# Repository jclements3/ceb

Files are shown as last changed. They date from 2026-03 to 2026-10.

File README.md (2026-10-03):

# CINVA-Ram Block Press

OpenSCAD model of a CINVA-Ram compressed earth block press.
All dimensions in inches. Material: 1/4" (0.250") steel plate unless noted.

Primary file: `cinva_ram.scad`

**14 x 7 x 4 shop drawings (recommended: the simple press).** `cinva_simple.py` is a faithful scale-up of the permies.com replica (thread 33406). His part drawings are `cinva1-7.jpg`; his SketchUp model and video show the assembly. Every part is scaled from his 11.5 x 6 x 3-5/8 brick (lengths x 1.217, widths x 1.167, heights x 1.102).

How it works:
- **Pressing:** the cam pin on his L-shaped head drops into the scoops at the peak of his V ramps. Pulling the handle over swings pin Q up over the cam pin like a knee, lifting the piston through the yoke. It locks 3 degrees past straight.
- **Latch:** his hook plates latch the head to the yoke for tilting.
- **Eject:** the yoke leans on his fixed pins, and pushing the handle down lifts the brick out.

Fixes to his drawings:
- the 2" side slot (his error; the supplier changed it to 1"), cut to pin + 1/16;
- the slot top kept below the loose soil;
- the fixed-pin height set for the eject stroke.

Heavier stock (listed with reasons in `ASSEMBLY.md`):
- 5/8 side plates;
- 3/4 AR400 ramps;
- 4140 pins (P 1-3/4", Q 1-1/4", cam 1-3/8");
- 3 x 1/2 yoke arms;
- the lid narrowed so the head clears it.

Checked at 150 psi working, 306 psi design (rev D: was 200 psi working):
- peak pull 98 lbf on the 90 in, 2 in sch 160 handle (rev G), under the 120 lbf CCOHS limit for pulling
  down above head height; 190 lbf if the soil needs 290 psi;
- about 92 lbf to eject (rev E: was 112);
- 23 part types, about 248 lb of steel;
- the press bolts to a 12 in welded steel stand (rev F, items 39-42, about 56 lb; Step 10 of `ASSEMBLY.md`);
- a feeder (rev C, items 24-38, about 53 lb): a funnel on a sliding feed box with a knife-gate floor,
  parked beside the press and slid over the mold to fill; see Step 9 of `ASSEMBLY.md`.

`cinva_ram_b123d.py` is the earlier heavy-duty version, kept for reference. It has a concave roller track, a central claw latch, and an eject roller on posts; its guide is `ASSEMBLY_full.md` and its drawings are in `drawings/14x7x4/`. Both models:
- solve the linkage for the fill, compress and eject positions;
- check every position and motion for collisions;
- run first-order strength checks.

`cinva_drawings.py` produces the ISO 128 set: general assembly with parts list, assembly views, operating positions, operation and design data, one detail sheet per part, DXF cut files, a PDF and a STEP assembly.

```
LD_LIBRARY_PATH=$HOME/miniconda3/lib python3 cinva_simple.py --check            # summary, strength and clearance checks
LD_LIBRARY_PATH=$HOME/miniconda3/lib python3 cinva_drawings.py --model simple   # -> drawings/simple-14x7x4/
LD_LIBRARY_PATH=$HOME/miniconda3/lib python3 cinva_animation.py                 # -> animation/press.json (simple press)
cd animation && python3 -m http.server   # then open http://localhost:8000 (#p5 jumps to phase 5, ?full shows the heavy press)

LD_LIBRARY_PATH=$HOME/miniconda3/lib python3 cinva_ram_b123d.py --check         # heavy-duty version
LD_LIBRARY_PATH=$HOME/miniconda3/lib python3 cinva_drawings.py --model full     # -> drawings/14x7x4/
LD_LIBRARY_PATH=$HOME/miniconda3/lib python3 cinva_animation.py --model full    # -> animation/press-full.json
```

The OpenSCAD model below (`cinva_ram.scad`) is the older interpretation of the scanned drawings; its lever geometry does not actually move the piston through a compression stroke.

## Parts by Assembly

### Brown — Pivot assembly (moves along ramp)
| Part | Description |
|---|---|
| **Pivot**  | Solid 2x2x6 block — holds handle, wings/tails pivot around it |
| **Wing** | Long toggle link (2 holes) — connects spacer pin to roller pin  |
| **Tail** | Short toggle link (1 hole) — connects spacer pin to pivot block |
| **Handle** | 6' round bar in pivot sunk hole (cylinder, no module) |

### Orange — Lever assembly (pivots around load pin)
| Part | Description |
|---|---|
| **Lever bar** | Long arm the operator pulls to press the brick (inline, `lever_bar_profile()`) |
| **Cross** | Cross bars welded between lever bars at grip end (inline cubes) |
| **Lever spacer block** | Block between crosses with roller hole (inline cube) |

### Pink — Clamp (rotates on axle)
| Part | Description |
|---|---|
| **Clamp**  | Hook-shaped bracket on axle that grabs the cross to lock the lever |
| **Grabber** | Plate between left and right clamp brackets |

### Purple — Pins and bars (round stock)
| Part | Description |
|---|---|
| **Fulcrum Pin** | Fixed pin through side plate holes |
| **Load Pin** | Pin in side slots, rises with lever mechanism |
| **Roller** | Rolls along ramp surface, drives the lever |
| **Spacer Pin**  | Through pivot/wing upper holes, moves with assembly  |
| **Axle** | 7/16" pin through front block, clamp rotates on this |

### Teal — Shelf assembly (rises to press brick)
| Part | Description |
|---|---|
| **Shelf** | Flat plate the brick sits on, rises in the side slots |
| **Bracket** | Vertical brace under shelf, connects shelf to piston plates |
| **Piston**  | Vertical plate pair connecting shelf to load pin |

### Red — Ramps and Top
| Part | Description |
|---|---|
| **Top**  | Flat plate on top of side plates — ramps sit on this |
| **Ramp** | V-shaped profile the roller rolls along to convert pull into downward press |

### Gray (ghost) — Structure
| Part | Description |
|---|---|
| **Side** | Tall vertical plate with piston slot, bolted to feet |
| **EndPlate** | Plate welded to shelf front/back edges, forms the brick chamber |

### White — Hinge (Top+Ramps swing open to eject brick)
| Part | Description |
|---|---|
| **Receiver** | Cylinder with 0.5" hole welded to Side plate — receives the pin |
| **Tab** | Tapered bracket welded to Top plate — butts against Ramp, conforms to Receiver |
| **Pin** | 0.5" dia cylinder welded to Tab, drops into Receiver |

### Green — Base
| Part | Description |
|---|---|
| **Base_Bracket** | L-shaped feet — bolts to ground, side plates mount to vertical leg |

## Animation

The model animates with OpenSCAD's `$t` variable (0 to 1):
- **t=0**: Roller at right side of ramp, lever tilted right
- **t=0.5**: Roller near peak, lever nearly vertical
- **t=1**: Roller past peak on left slope, lever tilted left

To render specific frames from the command line:
```
openscad -o frame.png -D '_t_override=0.5' cinva_ram.scad
```

## DXF Export

Run `export_dxf.sh` to export 2D projections of all parts as DXF files in `./dxf/`:
```
bash export_dxf.sh
```

## Reference Drawings

| Drawing | Description |
|---|---|
| cinva1.jpg | Sheet 1 — EndPlate (brick chamber walls) |
| cinva2.jpg | Sheet 2 — Wing and Tail (toggle links) |
| cinva3.jpg | Sheet 3 — Clamp bracket |
| cinva4.jpg | Sheet 4 — Lever bars and cross bars |
| cinva5.jpg | Sheet 5 — Ramp profile |
| cinva6.jpg | Sheet 6 — Side plate details |
| cinva7.jpg | Sheet 7 — Side plate and Piston |

## Reference Photos

| Photo | Description |
|---|---|
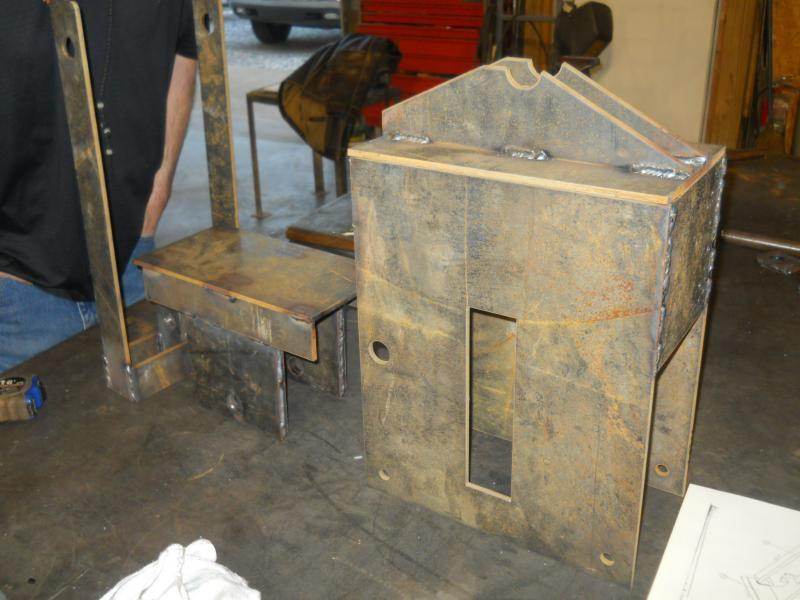
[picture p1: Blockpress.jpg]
|  | Baseboard frame and mold box sub-assemblies before final assembly |
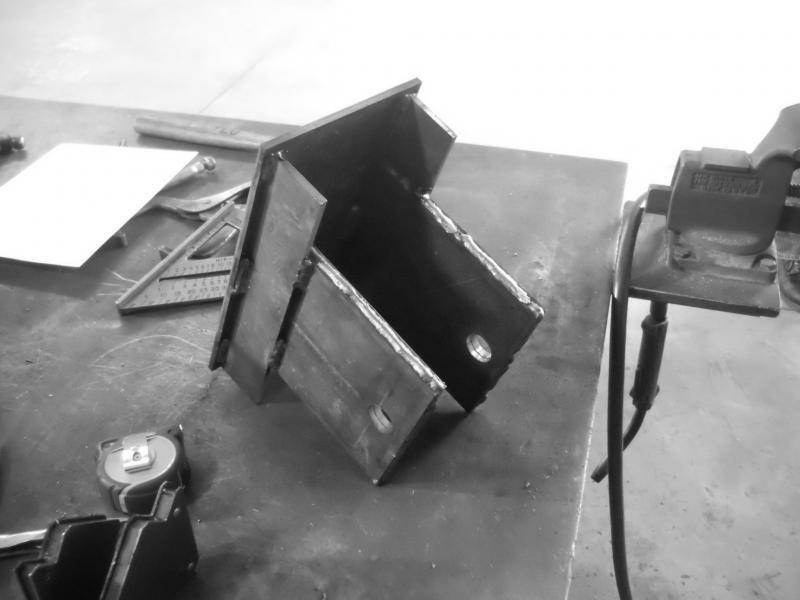
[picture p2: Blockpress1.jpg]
|  | Mold box welded, cover open showing hinge and interior |
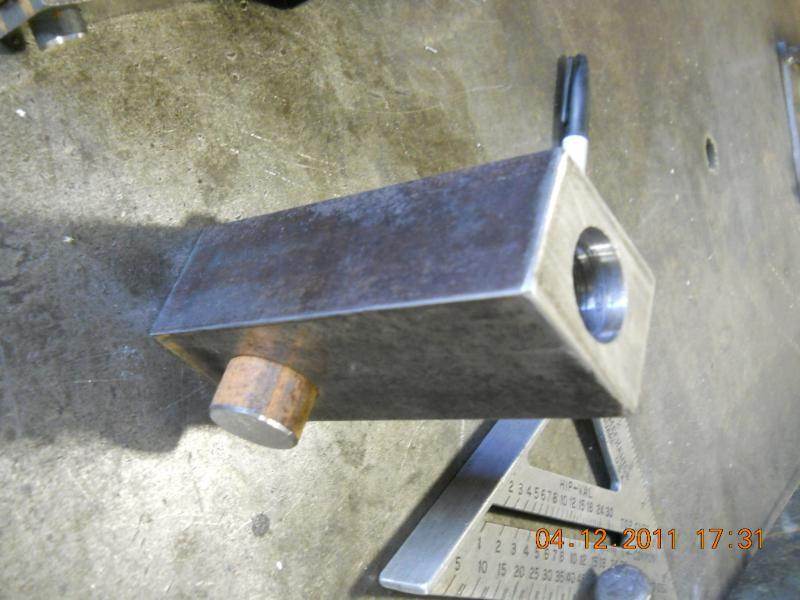
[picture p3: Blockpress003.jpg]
|  | Piston body close-up — rectangular with pivot hole and bronze bushing |
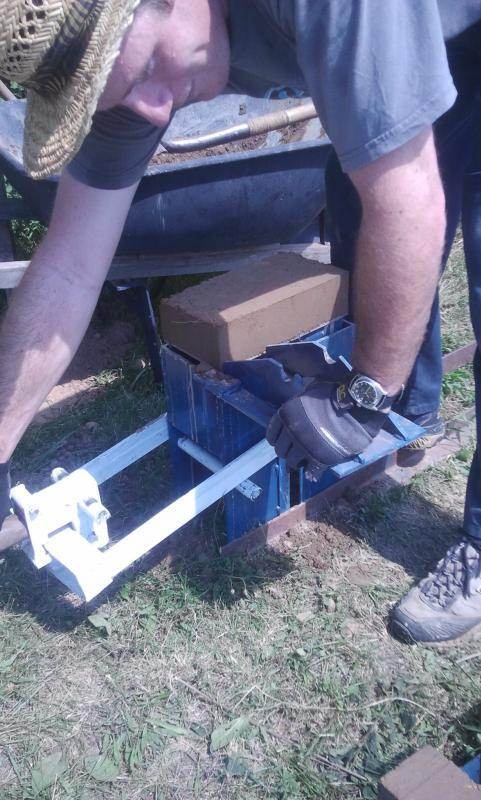
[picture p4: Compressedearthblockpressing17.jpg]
|  | Complete press in use, ejecting a compressed earth block |

---

# CETA-RAM Brick Making Machine

OpenSCAD and FreeCAD models of the CETA-RAM compressed earth block press,
based on the OHO e.V. engineering drawings (CC-BY-SA 4.0).

Brick size: **12" x 6" x ~4"** (compressed)

## Files

| File | Description |
|---|---|
| `ceta-ram/ceta_ram.scad` | OpenSCAD model — metric (mm), all 6 assemblies |
| `ceta-ram/ceta_ram_imperial.scad` | OpenSCAD model — imperial (inches), US steel sizes |
| `ceta-ram/ceta_ram_imperial.py` | FreeCAD Python macro — imperial, parametric |
| `ceta-ram/CETA_RAM_Imperial.FCStd` | Pre-built FreeCAD file (open directly) |
| `ceta-ram/CETA-RAM_Reference.md` | Complete BOM and dimensions from OHO drawings |

## Imperial Steel Sizes

| Metric | Imperial | Use |
|---|---|-----|
| 13mm plate | 1/2" | Sides, supports, brackets |
| 10mm plate | 3/8" | Base, top, piston plates |
| 6mm plate | 1/4" | Cap plate, side levers |
| 152x52x8 C-channel | C6x8.2 | Beams (2 pcs @ 18") |
| ∅60 rod | 2-3/8" | Main bars (2 pcs @ 18") |
| ∅44 rod | 1-3/4" | Handle (17-3/4") |
| ∅32 rod | 1-1/4" | Pins and rods |
| ∅20 rod | 3/4" | Support rod |
| ∅12 rod | 1/2" | Small pin |
| ∅70/60 tube | 2-3/4" OD / 2-3/8" ID | Piston rods |
| ∅44/32 tube | 1-3/4" OD / 1-1/4" ID | Piston rod 1, cap |
| ∅50/32 tube | 2" OD / 1-1/4" ID | Bushings |
| ∅40/20 tube | 1-1/2" OD / 3/4" ID | Support tubes |
| 2"x2"x1/4" angle | — | Cover levers (2 pcs @ 9-1/16") |
| M12/M14 bolts | 1/2"-13 | All fasteners |

## CINVA-Ram vs CETA-RAM Comparison

Both presses make a **12" x 6" x ~4"** brick, but the CETA-RAM produces
**cored bricks** (two 2-3/4" holes) while the CINVA-Ram makes **solid bricks**.

### Brick Weight Comparison

| Brick Type | Weight |
|---|---|
| CINVA-Ram (solid) | 20.0 lb |
| CETA-RAM (empty cores) | 16.7 lb |
| CETA-RAM + foam fill | ~16.8 lb |
| CETA-RAM + concrete fill | 20.8 lb |

### Wall Weight (8' wide x 6' tall = 144 bricks)

| Wall Type | Weight |
|---|---|
| Solid CINVA-Ram | 2,880 lb |
| CETA-RAM + foam + 1 bond beam | 2,468 lb |
| CETA-RAM all grouted | 2,995 lb |

### Recommended Cabin Wall Assembly (CETA-RAM)

- **Cores filled with closed-cell foam** — adds insulation (earth alone is ~R-0.2/inch)
- **Bond beams every 6'** — one course of grouted cores with horizontal rebar
- **Bond beam at top** — distributes roof load, ties walls together
- Result: thermal mass on both faces + insulation in middle + structural bond beams
- ~400 lb lighter per 8' wall section vs solid bricks
- 3 lb lighter per brick = less fatigue over thousands of bricks

## Reference Data

| Source | Location |
|---|---|
| Engineering drawings (53 pages) | `ceta-ram/pdf/` |
| STEP files (6 sub-assemblies) | `ceta-ram/cad/STP-files/Stp/` |
| Autodesk Inventor files | `ceta-ram/cad/CAD-files/Cad/` |
| AutoCAD 2D drawings | `ceta-ram/cad/DWG-files/` |
| Photos/renders | `ceta-ram/images/` |

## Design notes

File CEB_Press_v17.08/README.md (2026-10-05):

# OSE CEB Press v17.08

Open Source Ecology's **CEB Press v17.08**, Prototype 9 (2017). This is the latest working build in OSE's
CEB press genealogy: the hydraulic "Liberator" line, after v16.09. It simplified how the drawer bushings
are mounted.

Source: https://wiki.opensourceecology.org/wiki/CEB_Press_v17.08 (CC BY-SA).

## Contents

| Path | What it is |
|---|---|
| `source/CEB_17.08_CAD_Assembly.fcstd` | OSE's FreeCAD assembly (A2plus): eight sub-assemblies stored as BREP shells (unzipped in `source/fcstd/`) |
| `source/CEB_v1708_CAM.zip` | OSE master CAM nests: 1/8, 1/4 and 1/2 plate DXFs |
| `source/CEB_DXFs.zip` | OSE individual-part DXFs (partial; some fail to import) |
| `source/Seamanandschuske.zip` | OSE's 1/2 plate order, nested on 5 x 10 sheets |
| `source/subassemblies/` | OSE's per-sub-assembly FreeCAD files (with named parts), part folders, DXFs, pictures and the wiki page (from JC's download) |
| `source/*.html` | Owner's manual and genealogy wiki pages |
| `v1708_drawings.py` | Builds the ISO 128 set from the FreeCAD model (build123d + `../cinva_drawings.py`) |
| `drawings/` | `sheets/*.svg`, `dxf/` (flat parts), `CEB_Press_v17.08.pdf`, `CEB_Press_v17.08.step`, `manifest.json` |
| `shaker/` | Soil shaker (hopper vibrator) from OSE's *CEB a-z Build 1.0* manual: `shaker.py`, plus its own `drawings/` |

## Drawing set

* Sheet 1: general assembly, with a balloon for each of the eight sub-assemblies (S1-S8).
* Sheets 2-9: one per sub-assembly (Frame, Hopper Seat, Main Cylinder, Drawer, Arms, Hopper, Grate,
  Secondary Cylinder), with balloons and a parts list.
* Then one detail sheet for each distinct part: 76 parts, 246 pieces in total.
  * Mirror pairs and identical parts are drawn once, with their quantity.
  * Each part is laid flat on its largest face.
  * Flat plates also get a DXF.

The part names did not survive in OSE's file, so parts are named `<sub-assembly> NN` with stock and size.
Before cutting, check each part against OSE's CAM nests in `source/CEB_v1708_CAM.zip`.

```
export LD_LIBRARY_PATH=$HOME/miniconda3/lib
python3 CEB_Press_v17.08/v1708_drawings.py            # full set (~8 min)
python3 CEB_Press_v17.08/v1708_drawings.py --only 1,40 --no-pdf
python3 CEB_Press_v17.08/shaker/shaker.py             # shaker set
```

## Shaker

The shaker is modelled from two OSE sources:
* *CEB a-z Build 1.0*, steps 3-5 (pp. 15-20);
* OSE's weldment drawings 001-0042..0048 and 001-0077, in `OSE/ceb_press_cnc_package/reference/weldment_drawings`.

Where the two disagree, the weldment drawing is used. The guard outline comes from the manual. The
assembly sheet's arrangement is indicative: it follows the section on weldment 001-0048, sheet 2.

## Generated files

STEP exports (`*/drawings/*.step`) are gitignored: each drawing script writes its STEP when run. The PDFs, SVG
sheets and DXFs are kept in the repo for the web page and for shops without a build123d setup.

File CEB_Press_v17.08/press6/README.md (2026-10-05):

# OSE CEB Press 6 (a-z Build 1.0) — ISO 128 drawing set

Open Source Ecology's **CEB Press 6** ("The Liberator", Prototype 6, 2013, the Beddingfield edition): the
machine of the *CEB a-z Build 1.0* manual (`../CEB_a-z_Build_1.0.pdf`) and its cost / cut list
(`../CEB Press.ods`). Drawn with build123d and the repo's ISO 128 sheet code (`../../cinva_drawings.py`).

```
export LD_LIBRARY_PATH=$HOME/miniconda3/lib
python3 CEB_Press_v17.08/press6/press6_drawings.py -j 2          # full set
python3 CEB_Press_v17.08/press6/press6_drawings.py --only 1,35 --no-pdf
```

Output: `drawings/sheets/*.svg`, `drawings/dxf/*.dxf` (flat parts), `drawings/CEB_Press_6.pdf`,
`drawings/CEB_Press_6.step` (inches, coloured by module), `drawings/manifest.json` (same schema as
`../drawings/manifest.json`, plus `title`, `pdf`, `step`, `source`, `naming`, `purchased`, `dxf_checks`).

## Sources

| Source | Used for |
|---|---|
| `OSE/ceb_press_cnc_package/reference/full_assembly.stp` (OSE 01-001-00-6 main assembly) | All geometry. Read with OCP's XCAF reader so OSE's product names survive: every solid carries its OSE part number (`01-XXX-00-X`) and, for CNC plates, its library label (`L-XX`). |
| `../CEB Press.ods`, sheet *Final Cut List* | Manual part names. Its part numbers `100XXX` are OSE `01-XXX`; a cut-list name is used only when one of its lengths agrees with the model (±0.6 in). |
| *CEB a-z Build 1.0* (Simple Plates, Frame components, drawer, press feet pages) | A few more manual names (brick holder / dirt keeper plates, controller plate, feet, legs, press feet). |
| `OSE/.../reference/drawing_index.md` | 2011-12 BOM descriptions, 2015 weldment numbers / descriptions / stock. |
| `OSE/.../reference/2d_drawings/*.pdf` titles | Names of the assemblies; plates without a description are named after the assembly they are welded into (e.g. "Chamber Wall Plate L-F9"). |
| `OSE/.../dxf/*_steel_library.dxf` (original, not the 14x7 variant) | Cross-check of every `L-XX` plate: flat size and thickness against the model, noted on each sheet. Bent sheet parts get their flat blank from the DXF. |

## Organisation

Sheet 1 general assembly (modules ballooned S1-S9) · sheets 2-10 one per module of the manual
(Main Frame, Press Cylinder and Foot, Arms, Feet and Legs, Drawer, Hopper, Grate, Soil Shaker, Controls) ·
then one detail sheet per OSE part number (identical parts once, with the total quantity; the module is the one
that uses it most, the notes list every use). Purchased parts (cylinders, valves, hinges, bushings, printed
plastic, couplers, fittings) and fasteners are in the STEP and listed on the module sheets / in the manifest, not
detailed. Fasteners are left out of the assembly views.

## Naming and checks

See `naming` and `dxf_checks` in `drawings/manifest.json` and the summary at the end of `build.log`.
* 84 OSE part numbers detailed (238 fabricated pieces in 9 modules); 486 STEP solids in all, 141 of them
  fasteners and 107 other purchased / printed parts.
* Part identity: 84 / 84 (100 %) from the STEP's own OSE part numbers and L-labels.
* Descriptive names: 47 / 84 from the a-z cut list (length-checked), the manual or OSE's drawing index;
  35 more named after the OSE assembly they are welded into (2D drawing title, e.g. "Saddle Plate L-Q3");
  2 left as "Part 01-xxx" / "Plate L-H19" (parts of 01-236, which has no OSE drawing).
* DXF cross-check: 67 L-labelled plates; 57 match the original CNC outline (size and thickness within
  0.06 in); 4 are bent 1/8 sheet parts (L-H4, L-H5, L-H10, L-H12; blank size from the DXF);
  L-A6, L-Q12, L-G1, L-G2 differ from the library outline (noted "CHECK" on their sheets);
  L-Q2 and L-H19 have no outline in the original libraries.

## Known gaps and inconsistencies

* OSE's 2D set title blocks say **"CEB PRESS 5"** although the package is Press 6 (top-level 01-001-00-6).
* **The a-z Build 1.0 manual builds a later, structural-shape version** of parts of this machine; these are
  in the manual / cut list but not in the STEP (the STEP is the CNC-plate machine):
  - soil shaker from L4x4 angle (21 in and 8 in), 1 in rebar braces and a 2x2-angle-framed guard — drawn
    separately in `../shaker/` (the STEP's shaker is the plate version, L-O2..L-O5, drawn here);
  - roller guides (V-groove bearings on a 1/2 x 2 x 16 main plate) — the STEP uses 1 in guide rods in printed
    / nylon bushings (01-220, 01-236);
  - drawer outer / inner rails (3/16 x 2-1/2 and 1/2 x 2 x 36), back (L4x7 angle), spacer (6x6 tube);
  - main-frame small components: sensor holders, magnet holder, thin / wide cylinder supports, dirt blockers
    (2x2 angle), horizontal-member reinforcements;
  - hopper mounting plates and hinge plates; legs 2x2x1/4 x 48 (STEP legs 01-155 are 3/16 wall x 36);
  - the electronics (sensor unit, solenoid driver, controller box) and hydraulic hoses.
* Several OSE part numbers are reused between the 2011-12 set and the a-z cut list for different stock
  (e.g. the frame channels L-F1 / L-F2 are 1/2 plate in the STEP, C6x13 in the 2015 weldment redraw and the
  cut list); each sheet draws the STEP part and notes the alternative.
* The STEP has the same part number on mirror-image parts (left / right primary arms share 01-009, 01-010,
  01-272); they are drawn once, quantity 2.
* L-labels in the DXF libraries but not in the STEP: L-D9 is in the STEP as 01-028-00-2; L-H7 and L-Q10 are
  printed-plastic parts; L-H14, L-O10, L-Q16 have no STEP part. L-O9 is in the STEP as 01-143, typed "L-09".

## Rebuilding from a fresh clone

`press6_drawings.py` uses OSE's files from `OSE/ceb_press_cnc_package/` (from `OSE/get_ceb_plans.sh`) when that
folder exists. Otherwise it fetches OSE's main-assembly STEP (`01-001-00-6.stp`), the 2D drawing set
(`CEBVI_2D_DRAWING_PDF.zip`) and the three CNC DXF libraries from the OSE wiki into `source/ose/`, which is
gitignored. The drawing cross-reference index (`source/drawing_index.md`) and the DXF cluster extractor
(`extract_parts.py`, from `OSE/freecad/`) are kept here. The STEP export in `drawings/` is not tracked: run the
script to make it.

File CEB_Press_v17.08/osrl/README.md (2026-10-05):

# OSRL "Resilient Living" CEB press, rev 1.1: build123d clone

This is a clone of the **Open Source Resilient Living CEB press, rev 1.1**:
* *OSRL CEB Press Drawings 1-1*: 11 sheets, Dec 2011, design team Damien Gendron and Butte Metz.
* The OSRL *Manual CEB Press*.
* Licence: CC BY-SA 3.0, www.osrliving.org.
* Source PDFs: `../pdfcoffee.com_osrl-ceb-press-drawings-1-1-2-pdf-free.pdf` and `../pdfcoffee.com_manual-ceb-press-pdf-free.pdf`.

It is a manual CINVA-type press for a 12 x 6 x 4 block with two 2-3/8 cores.
* **Frame:** two C6x13 channels on a base plate, with 1/4 side plates. Two 2 in pipe guide rods form the cores.
* **Piston:** a lower insert on two pipe guides, carried on a 1 in pin by a two-arm yoke.
* **Toggle and latch:** the toggle has a square-tube body that takes a 48 in pipe lever, and two 2 in followers. A latch hooks the lever to the yoke.
* **Lid:** hinged and counterweighted. Its two rails climb to a 2 in scoop that seats the followers.
* **Ejection:** the yoke tilts onto two eject rollers on the front channel.

## Files

| Path | What it is |
|---|---|
| `osrl_press.py` | Parametric model: every part on their 11 sheets, kinematics, poses, strength checks, functional checks and collision sweeps (`--check`) |
| `build_drawings.py` | ISO 128 drawing set built with `../../cinva_drawings.py`, output to `drawings/` |
| `drawings/` | `sheets/*.svg` (4 assembly sheets + 42 part sheets), `dxf/`, `OSRL-CEB-Press_12x6x4.pdf`, `.step`, `manifest.json` |
| `build_animation.py` | Exports `animation/press.json` |
| `animation/index.html` | The repo's three.js viewer, extended for the toggle pivot sitting off the yoke axis |
| `check.log` | Last `--check` results |

```
export LD_LIBRARY_PATH=$HOME/miniconda3/lib
python3 CEB_Press_v17.08/osrl/osrl_press.py --check      # summary, strength, functional checks, collision sweeps
python3 CEB_Press_v17.08/osrl/build_drawings.py          # ISO 128 set
python3 CEB_Press_v17.08/osrl/build_animation.py         # animation/press.json
cd CEB_Press_v17.08 && python3 -m http.server             # then open /osrl/animation/
```

## How the press works (as reconstructed)

1. **Stand up.** With the lever latched along the yoke, standing the yoke up rolls the followers up the rail slopes. They drop into the scoops with the piston still on the bottom (0.04 in off). This is the manual's "letting the lower rollers fall into place".
2. **Press.** Release the latch and pull the lever over to horizontal toward the rear channel. The toggle turns about the seated followers and lifts the piston 3.5 in. At horizontal it is at dead centre.
3. **Block thickness.**
   * The head bolts into arm holes 1-5, giving blocks of 7.06, 6.07, 5.08, **4.09** and 3.10 in from a 7.625 in loose fill.
   * Hole 4 gives the 4 in block, matching the manual's "adjustable in 1 in increments".
4. **Eject.** The arms rest on the eject rollers. The axle sits in the 7 in hole, as drawn on sheet 2. Pushing the lever down ejects the block: the yoke tilts from 38 to 88 deg and the lever end ends 17 in off the ground.

## Placements the drawings leave open

* **Toggle:** it sits behind the yoke head, on the side the lever swings to. It pivots in pivot mounts 2-3/4 behind the arm centre line, with the followers 2.875 behind the toggle axle when the lever is upright.
  * The other way round, the lever would hit the head bodies before it reached horizontal.
  * The followers sitting at the yoke line at standing-up is consistent with sheet 1.
  * Their sheet-1 3D view shows the yoke leaning forward with the toggle above the head.
* **Toggle axle height:** 3-3/4 below the head top, with the pivot mounts' top edge on the head bodies.
  * Sheet 1 scales to 1/2 lower. That would make a 3.6 in block at hole 4 and seat the followers with the piston 1/2 off the bottom, so the touching layout is used.
* **Counterweight arm hinge hole:** not dimensioned. It is placed 1-1/2 from the block's rear end and 15/16 up, which puts the pin at the lid's hinge edge as on sheet 9.
* **Lid hinge:** detail A puts the hole over the side plates' front edge, 1-1/8 above their top.

## Deviations

* **Hinge pin:** 5/8 long, not their 1-3/8. Longer, it fouls the followers (inside) or the yoke arms (outside).

## Findings (their design as drawn)

See `check.log` for the full list. The design notes and the strength table are on sheet 4 of the drawing set.

* **Lever force.**
  * The manual quotes 80 lbf. On the 48 in lever, 80 lbf makes only about **80 psi**.
  * 200 psi needs about 200 lbf, which is two people.
* **Strength at 300 psi (overfill design load).** These parts are over allowable:
  * the 1/4 side plates: they span 12 in between the channel flanges with no stiffener;
  * the 3/16 lid, both between and outside the rails;
  * the lid and rails as a beam;
  * the 1 in piston pin, which is 1-1/8 out from the piston side to the arm;
  * the toggle axle;
  * the 1-1/4 sch 40 lever.

  At their 80 psi most of these pass.
* **Counterweights vs the yoke head.**
  * With the yoke resting on the eject rollers, the counterweights sit against the head bodies.
  * Swinging the lid open or shut, the counterweights pass through the head and pivot mounts.
  * They only clear once the lid is fully open: 74 deg, where it rests on the front channel.
  * This is a reconstruction-level finding: it depends on the open placements above.
* **Start pose.** With the followers seated, the yoke leans 17 deg forward. The head's front corner then meets the counterweight-arm blocks and the hinge pins at the lid's hinge edge, and the pivot mounts touch the lid's front edge.
* **No over-centre stop.** The lever stops at dead centre (horizontal) with no positive stop, so the operator holds it there.
* **Lid in the block's path.** At 74 deg the lid leans over the front of the mold, so a rising block meets it unless the lid is lifted further by hand.

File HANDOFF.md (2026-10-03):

# Handoff — simple CINVA-Ram press, 14 x 7 x 4 (rev G)

For the next Claude session picking this up. Owner: JC (6'1"; direct; wants working deliverables, not
documentation; correct reasoning errors immediately; no unnecessary questions or verbosity).

## State

- Branch `next` = upstream `master` (9cdb75c) + 16 commits; `patches/0001-0016` are the same commits.
- Drawings rev G (sheets 1, 2, 4, 23), rev F (the other 42). 42 items: press 1-23, feeder 24-38, stand 39-42.
- Working pressure 150 psi (assumption, see open items), design load 306 psi. Handle 90 in, 2 sch 160.
- `cinva_simple.py --check`: 19 functional checks pass, every strength check within allowable.
- `sysml_sync.py`: exit 0, no drift. All three SysML files pass the OMG pilot (2026-08).

## Environment

```
pip install "build123d==0.11.1" cairosvg jupyter_client   # 0.12+ removed Vertex.to_tuple (cinva_drawings)
# SysML pilot kernel (Java 17+), pinned + hash-checked:
curl -LO https://github.com/Systems-Modeling/SysML-v2-Pilot-Implementation/releases/download/2026-08/jupyter-sysml-kernel-0.62.0.zip
sha256sum jupyter-sysml-kernel-0.62.0.zip  # 5a015ed3f2b3d2dae14e9c3fb9602d9e1fef5f9ce33cf396c422329405cc3cb2
unzip jupyter-sysml-kernel-0.62.0.zip -d sysml-kernel && python3 sysml-kernel/install.py --user
```
JC's own machine needs `LD_LIBRARY_PATH=$HOME/miniconda3/lib` for build123d (see CLAUDE.md).

## Commands (each full run is ~3-6 min)

| Command | What |
|---|---|
| `python3 cinva_simple.py --check` | strength rows + 19 functional checks incl. full collision sweep |
| `python3 sysml_sync.py [--update] [--no-sweep]` | drift model<->code, run solver, write `CinvaRamResults.sysml`; exit 1 drift, 2 failed check/requirement |
| `python3 sysml_lint.py CinvaRam.sysml CinvaRamResults.sysml CinvaRamTrade.sysml` | parse/resolve with the pilot |
| `python3 sysml_trade.py` | cam pin x side plate trade, cached in `trade_cache.json` (delete it after any design change) |
| `python3 cinva_drawings.py --model simple [--only key,...] [--no-pdf]` | ISO 128 sheets, DXF, STEP, PDF |
| `python3 cinva_animation.py` | `animation/press.json` for `animation/index.html` |

## Conventions (learned the hard way)

- **Revisions:** `REVISIONS`, `CURRENT_REV`, `SHEET_REV` in `cinva_simple.py`. Bump only sheets whose
  content changed: regenerate with `--no-pdf`, compare sorted SVG path sets against `HEAD`, set `SHEET_REV`
  for those, regenerate with PDF, then `git checkout` the other sheets and all unchanged DXFs (they differ
  only by timestamps/GUIDs/path order).
- **Model sync:** design params in `CinvaRam.sysml` use `default` (variants can override), derived values
  are bound. `sysml_sync.py --update` rewrites params/BOM from the code; requirement limits are read from
  the model and checked in Python (the pilot cannot evaluate unit-bearing expressions).
- **SysML pitfalls:** `frame` is a keyword; nested states are referenced as `fill.returned` from outside.
- **Requirements are sourced:** HandleForceLimit 120 lbf = CCOHS Table 2 "pull down, above head height"
  (the peak pull comes 71% through the head rotation with the grip ~76 in up). PartHandlingLimit 51 lb =
  NIOSH RNLE load constant. No total-steel cap (no basis for one).
- **Run long jobs detached** (`setsid nohup ... &`) and poll; tool calls time out at 300 s.

## Open items / decisions pending

1. **Soil test (blocking).** The press compresses a fixed 6.75 -> 4.0 fill (1.69:1); the pressure is set by
   the soil, not the operator. Test JC's mix at 1.69:1 in a pipe mold under a jack with a gauge. On the 90 in
   handle: peak pull ~0.65 lbf per psi (98 lbf at 150 psi, 120 lbf at ~183 psi, 190 lbf at 290 psi).
   Literature: 1-2 MPa minimum molding pressure, 2-4 MPa for good stabilized blocks; CINVA-Ram ~2 MPa.
2. **One-person at 290 psi** is not possible with this knee: sweeping `psi0` bottoms out at 155 lbf and
   breaks the eject-grip check. Average pull is 87 lbf, so a profiled cam (shaped track) could reach
   ~100-110 lbf; alternatives: hydraulic bottle jack, two operators. JC has not chosen.
3. **Margins to watch:** handle 50.3 lb vs the 51 lb part limit; yoke arms 0.16 above the stand top at eject;
   peak pull at 150 psi is fine, but the 150 psi itself is unverified.
4. **Unverified:** animation feeder motion not viewed in a browser (JS syntax-checked only); feeder chute
   flow and gate shear are design assumptions; no prototype or load test (ASSEMBLY.md Step 8).
5. **Known compromise:** the open knife gate leaves the far 3/16 of the mold width under the gate.

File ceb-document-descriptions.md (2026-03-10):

Here's a list of the documents that would likely be required for the delivery and construction of the Manual Compressed Earth Brick (CEB) Press, adhering to GEIA-STD-0007 principles and best practices:

**1. Performance Specification (DI-MISC-80005C or DI-MISC-80011B):**

*   This is the core document you already have, detailing the functional requirements of the CEB press. It establishes the performance, design, safety, and quality criteria that the delivered product must meet.

**2. Engineering Drawings and Technical Data Package (TDP):**

*   **Assembly Drawings:** Detailed, dimensioned drawings showing how all the parts fit together to form the complete CEB press.
*   **Part Drawings:** Individual drawings for each component, specifying materials, dimensions, tolerances, finishes, and any special manufacturing instructions.
*   **Bill of Materials (BOM):** A comprehensive list of all parts, materials, and standard components (e.g., fasteners) required for assembly, including quantities and part numbers.
*   **Material Specifications:** If any unique or non-standard materials are used, detailed specifications for these materials should be provided.

**3. Quality Assurance Plan (QAP):**

*   This document outlines the manufacturer's quality control processes to ensure that the CEB press meets the specifications. It may include inspection procedures, testing methods, and acceptance criteria.

**4. User Manual:**

*   As mentioned in the specification, a detailed user manual is crucial. It should cover:
    *   Step-by-step assembly instructions with clear diagrams.
    *   Operational procedures and best practices for optimal brick production.
    *   Maintenance guidelines, including recommended lubrication schedules and troubleshooting tips.
    *   Parts list with diagrams for easy identification and ordering of replacements.

**5. Warranty Documentation:**

*   The manufacturer's warranty statement should be included, specifying the duration and terms of the warranty coverage. This provides the buyer with assurance of the product's quality and the manufacturer's commitment to address any defects.

**6. Test Reports (Optional):**

*   If the manufacturer has performed any testing to validate the press's performance, such as compression tests on the produced bricks, the test reports could be included to provide additional evidence of compliance with the specification.

**7. Transportation and Packaging Instructions:**

*   If the CEB press requires special handling or packaging for transport, detailed instructions should be included to prevent damage during shipping.

**Additional Considerations:**

*   **Training Materials:** Depending on the complexity of the press, the manufacturer might provide training materials, such as videos or online tutorials, to assist users in operating and maintaining the equipment effectively.
*   **Maintenance and Repair Kits:** If specialized tools or spare parts are needed for maintenance, the manufacturer could offer them as optional kits.

**Important Note:**

The specific documents and level of detail required may vary depending on the complexity of the CEB press, the specific procurement contract, and any applicable regulations or standards. It's essential to tailor this documentation package to meet the needs of both the manufacturer and the end-user.

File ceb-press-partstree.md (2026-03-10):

---
title: "Performance Specification for Manual Compressed Earth Brick (CEB) Press"
geometry: - margin=1in
fontsize: 12pt
documentclass: article
header-includes:
 - \usepackage{multicol}
 - \setlength{\columnsep}{0.25in}
 - \usepackage{fancyhdr}
 - \pagestyle{fancy}
 - \fancyhf{}
 - \renewcommand{\headrulewidth}{0pt}
 - \renewcommand{\footrulewidth}{0pt}
---

**Document ID: DI-MISC-80005C**  (or DI-MISC-80011B if emphasis is on hand tool aspect)

## 1. Scope

1.1 This performance specification establishes the requirements for a manually operated Compressed Earth Brick (CEB) Press, used for on-site production of standardized earth bricks in construction projects. The CEB press is designed to be sustainable, cost-effective, and suitable for regions where access to conventional building materials may be limited.

## 2. Referenced Documents

2.1 The following documents, of the issue in effect on the date of the solicitation, form a part of this specification to the extent specified herein:

*   **ASTM D698:** Standard Test Methods for Laboratory Compaction Characteristics of Soil Using Standard Effort (12,400 ft-lbf/ft³ (600 kN-m/m³))
*   **ASTM D1557:** Standard Test Methods for Laboratory Compaction Characteristics of Soil Using Modified Effort (56,000 ft-lbf/ft³ (2,700 kN-m/m³))

## 3. Requirements

### 3.1 Applicable Documents

The following documents, of the issue in effect on the date of the solicitation, form a part of this specification to the extent specified herein:

*   **DI-MISC-80005C:** Performance Specification for Mechanical Items (or DI-MISC-80011B if emphasis is on hand tool aspect)

### 3.2 Requirements

#### 3.2.1 General

*   The CEB press shall be a manually operated, lever-action press designed for the compaction of soil mixtures into standardized brick shapes.
*   The press shall be lightweight (not to exceed [specify weight] kg), portable, and easy to assemble and disassemble without special tools for transportation and on-site use.

#### 3.2.2 Materials and Construction

*   The press shall be constructed of durable materials resistant to corrosion and wear, suitable for outdoor use in varying environmental conditions (-20°C to 50°C).
*   Steel components shall be treated with a rust-inhibiting coating compliant with [specify standard, e.g., ISO 12944].
*   All fasteners shall be corrosion-resistant stainless steel.

#### 3.2.3 Design

*   The press shall incorporate an ergonomic lever mechanism with a mechanical advantage of at least [specify value] for applying compressive force.
*   The mold shall be readily interchangeable to produce bricks of standardized dimensions (length: [specify], width: [specify], height: [specify]), ensuring consistent density and compressive strength.
*   The mold shall be easily removable for cleaning and maintenance, requiring no tools.
*   The press shall incorporate a reliable mechanism for ejecting the compacted brick from the mold, minimizing damage risk.

#### 3.2.4 Performance

*   The press shall be capable of producing bricks with a minimum compressive strength of [specify value] MPa, as determined by ASTM D698 or D1557.
*   The press shall be capable of producing bricks with a density of [specify value] kg/m³.
*   The press shall be capable of producing at least [specify value] bricks per hour with a single operator under normal operating conditions.

#### 3.2.5 Safety

*   The press shall comply with all applicable safety standards and regulations.
*   The press shall be stable during operation on level ground, with a tip-over angle of at least [specify value] degrees.
*   Moving parts shall be guarded or shielded to prevent accidental contact.
*   The lever shall incorporate a positive locking mechanism to prevent unintentional release during operation.

## 4. Quality Assurance Provisions

4.1 The CEB press shall be inspected and tested by the manufacturer to ensure compliance with all specified requirements.

4.2 The manufacturer shall provide a warranty for the press, covering defects in materials and workmanship for a period of [specify duration] from the date of delivery.

## 5. Preparation for Delivery

5.1 The CEB press shall be cleaned, lubricated (if applicable), and prepared for shipment.
5.2 The press shall be disassembled into its major components for packaging and transportation to minimize shipping volume.
5.3 A comprehensive user manual shall be included, providing detailed instructions for assembly, operation, maintenance, troubleshooting, and parts list with diagrams.

## 6. Notes

6.1 This performance specification provides the minimum requirements. Proposals exceeding these requirements may be considered favorably.
6.2 The government reserves the right to conduct verification testing to confirm compliance with this specification.

**Additional Notes:**

*   The "Sources" section is omitted, as it's not typical in a specification.
*   The "Parts List" would likely be a separate document, possibly referenced within the user manual.
*   Specific numerical values need to be filled in based on the project's needs.
*   This is still a draft; tailoring to the exact procurement process is needed.

## Sources

* http://multimedia.3m.com/mws/media/183536O/sprs20-3mtm-diamond-gradetm-fluorescent-roll-up-sheeting.doc&fn=SPRS24.doc
* http://bjrbe-journals.rtu.lv/article/view/bjrbe.2022-17.565
* http://koreascience.kr/article/JAKO202007835829157.page

# Parts List

Ideally, the final brick size should be slightly smaller than 6x12 inches. certainly no bigger. This
is to make room for a little mortar or sealant. Approximately 1/16" off each dimension is
suggested. Grinding or milling 1/32 inches off both sides of the vertical channels is one possible
solution. Milling slots into the side plates would work also.

## Piston Assembly

### Plate Stiffener (2 pcs)

Material: 1/4 X 1" Steel Bar

### Top Plate

Material: 1/4" Steel Bar

### Lower Insert

Material: Various (Aluminum, Plastic, Wood)

### Piston Guide (2 pcs)

Material: 2 1/2 Steel Pipe (SCH 40)

### Pivot Tube

Material: 1" Steel Pipe (SCH 40)

### Piston Side (2 pcs)

Material: 1/4" Steel Bar

### Piston Pin

Material: 1" CRS Round

### Pin Spacer (2 pcs)

Material: 1 1/2" CRS Round

## Body Assembly

### Rod Top (2 pcs)

Material: 1/4" Steel Plate

### Rod Bottom (2 pcs)

Material: 3/8" Steel Plate

### Guide Rod (2 pcs)

Material: 2" Steel Pipe (SCH 40)

### Lid Hinge (2 pcs)

Material: 1/8 X 1 1/2" Steel Bar

### Front Channel

Material: C6x13 Steel Channel

### Eject Roller (2 pcs)

Material: 2" CRS Round

### Eject Axle

Material: 3/4" CRS Round

### Base Plate

Material: 1/4 X 6" Steel Bar

### Outrigger Mount (4 pcs)

Material: C3x6 Steel Channel

### Side Plate (2 pcs)

Material: 1/4 X 8" Steel Bar

### Rear Channel

Material: C6x13 Steel Channel

## Outrigger Assembly

### Outrigger (2 pcs)

Material: C3x6 Steel Channel

### Mounting Tab (2 pcs)

Material: 5/16 X 2 Steel Bar

## Yoke Assembly

### Lever

Material: 1 1/4" Steel Pipe (SCH 40)

One end of the lever will need to have flats ground into it in order to fit into the toggle's square tube.
Do not weld the lever to the toggle.

### Yoke Arm

Material: 3/8 X 2 1/2" Steel Bar

### Yoke Head

#### Head Body (2 pcs)

Material: 3/8 X 2 1/2 Steel Bar

#### Head Side (2 pcs)

Material: 3/8 X 2 1/2 Steel Bar

#### Pivot Mount (2 pcs)

Material: 3/8 X 2 1/2" Steel Bar

### Toggle

#### Latch Hook

Material: 1/8" Steel Plate

#### Toggle Body

Material: 3/16 X 2" Steel Square Tube

#### Lower Toggle

Material: 3/8 X 2 1/2 Steel Bar

#### Latch Body

Material: 1/8 X 1 1/2" Steel Bar

#### Latch Handle

Material: 1/4" Crs Round

### Follower

#### Toggle Axle

Material: 1" CRS Round

#### Follower Axle

Material: 1" CRS Round

#### Toggle Follower (2 PCS)

Material: 2" CRS Round

#### Latch Pivot

Material: 1/4" Crs Round

## Lid Assembly

### Counterweight Pin (2 pcs)

Material: 1/2" Steel Round

### Counterweight (2 pcs)

Material: 3 1/2" Steel Round

### Counterweight Arm (2 pcs)

Material: 1/8" Steel Plate

### Lid Rail (2 pcs)

Material: 1/4" Steel Plate

### Lid

Material: 3/16" Steel Plate

### Hinge Pin (2 pcs)

Material: 3/8" Steel Round

### Upper Insert (2 pcs)

Material: Various (Aluminum, Plastic, Wood)

### Spacer

Material: Various (Plastic, Wood)

Multiple spacers of different thicknesses will be needed to set the dirt charge. 2, 1, 1/2 and 1/4" would be useful.

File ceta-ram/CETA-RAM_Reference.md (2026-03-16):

# CETA-RAM Brick Making Machine — Reference

**Source:** https://en.oho.wiki/wiki/Brick_Making_Machine_CETA-RAM_-_for_soil_bricks
**Organization:** Centro de Experimentación en Tecnología Apropiada (CETA)
**Redesigned by:** OHO e.V. — J. Rosciano (created), A. Morillo (approved)
**Version:** 1.1, Date: 28/07/2021
**License:** CC-BY-SA 4.0
**Units:** All dimensions in mm

## Overall Dimensions
- Height: 467 mm (lever up), 588 mm (front view)
- Width: 532 mm
- Length: 788 mm (press body), 924 mm (with lever)
- Platform: 2000 x 400 x 121 mm

---

## Complete Parts List (BOM)

### Assembly A — Documents
| POS | Part Name | File Name |
|-----|---|---|
| A1 | 3d views | ceta_bbmcr_brick-making-machine-ceta-ram.iam |
| A2 | Exploded 3d view | ceta_bbmcr_brick-making-machine-ceta-ram.ipn |
| B1/B2 | Parts list | ceta_bbmcr_brick-making-machine-ceta-ram.csv |
| C1 | Technical notes | — |

### 1.0 Structure Assembly (Structure.iam)
| POS | QTY | Part Name | Specifications | Dimensions (mm) |
|-----|-----|---|---|---|
| 1.1 | 2 | Side | Thk 13 ASTM A36 | 344 x 203 x 13 |
| 1.2 | 1 | Base structure | Thk 10 ASTM A36 | 432 x 152 x 10, 4x∅13 holes, 2xM14x2-6H tapped |
| 1.3 | 1 | Beam 1 | 152x52x8 ASTM A36 (C-channel) | 457 long, ∅20 hole at 181 from end, 26 from bottom |
| 1.4 | 1 | Beam 2 | 152x52x8 ASTM A36 (C-channel) | 457 long (no hole) |
| 1.5 | 1 | Cap insurance | OD 44 DIN C45 | ∅44 OD / ∅32 ID, 52 long (tube) |
| 1.6 | 1 | Cap insurance 1 | Thk 6 ASTM A36 | 52 x 40 x 6 (plate) |
| 1.7 | 2 | Support structure | OD 40 DIN C45 | ∅40 OD / ∅20 ID, 36 long (tube) |
| 1.8 | 1 | Support structure 1 | OD 20 DIN C45 | ∅20 solid rod, 248 long, 2xR3 grooves |
| 1.9 | 2 | Bars structure | OD 60 DIN C45 | ∅60 solid rod, 457 long |
| 1.10 | 2 | Bolts structure | M14x30 DIN 933 | Standard |
| 1.11 | 4 | Bolts | M12x100 DIN 931-1 | Standard |
| 1.12 | 4 | Nuts | M12 DIN 439-2 | Standard |
| 1.13 | 4 | Washer | DIN 125-1 | Standard |
| 1.14 | 2 | Cotter pins structure | DIN EN ISO 1234 | Standard |

**Structure assembly dims:** 423 wide (outer), 344 (inner), 565 tall, 191 deep, 432 base width. Top holes ∅40 and ∅20.

### 2.0 Top Assembly (Top assembly.iam)
| POS | QTY | Part Name | Specifications | Dimensions (mm) |
|-----|-----|---|---|---|
| 2.1 | 1 | Top | Thk 10 ASTM A36 | 406 x 178 x 10, ∅32 hole at 28 from edge, 136 from bottom |
| 2.2 | 2 | Top support | Thk 13 ASTM A36 | 304 x 51 x 13, R25 hook end, 18° angle, 127 slot, 190 total |
| 2.3 | 1 | Bottom top | OD 32 DIN C45 | ∅32 solid rod, 105 long |
| 2.4 | 1 | Bottom top 1 | Thk 13 ASTM A36 | 97 x 13, R2 chamfers, 93 between chamfers, 4x65° chamfer |

**Top assembly dims:** 304 x 96 top view, 406 wide, 178 tall, 156 high profile, 61 overhang, 28 offset, 65° angle, 18° ramp.

### 3.0 Piston Assembly (Piston assembly.iam)
| POS | QTY | Part Name | Specifications | Dimensions (mm) |
|-----|-----|---|---|---|
| 3.1 | 1 | Piston top | Thk 10 ASTM A36 | 320 x 152 x 10, 2x∅70 holes at 77 spacing, 76 from bottom |
| 3.2 | 2 | Piston caps | Thk 10 ASTM A36 | 216 x 152 x 10, ∅44 hole at 44 from edge, 76 from bottom |
| 3.3 | 2 | Piston caps 1 | Thk 10 ASTM A36 | 305 x 38 x 10 |
| 3.4 | 2 | Piston rod | OD 70 DIN C45 | ∅70 OD / ∅60 ID, 254 long (tube) |
| 3.5 | 1 | Piston rod 1 | OD 44 DIN C45 | ∅44 OD / ∅32 ID, 190 long (tube) |

**Piston assembly dims:** 160 wide, 254 tall (front), 190 deep, 182 inner height, 90 top width, 22 side gap, 48+42 top offsets. Holes: ∅70 and ∅60 at 76 and 77 spacing, 84 center offset, 44 bottom offset.

### 4.0 Support Assembly (Support assembly.iam)
| POS | QTY | Part Name | Specifications | Dimensions (mm) |
|-----|-----|---|---|---|
| 4.1 | 2 | Support piston | Thk 13 ASTM A36 | 636 x 64 x 13, 2x∅32 holes at 38 and 108 from ends, 32 from bottom |
| 4.2 | 2 | Support piston 1 | Thk 13 ASTM A36 | 208 x 64 x 13 |
| 4.3 | 2 | Bar support | Thk 13 ASTM A36 | 64 x 51 x 13, ∅32 hole at 32 from edge, 26 from bottom |
| 4.4 | 1 | Axis support | OD 32 DIN C45 | ∅32 solid rod, 266 long, 2xR3 grooves, 16 diameter at grooves |
| 4.5 | 2 | Internal support | Thk 13 ASTM A36 | 126 x 64 x 13, ∅32 hole at 32 from edge, 32 from bottom |
| 4.6 | 2 | Cotter pins support | DIN EN ISO 1234 | Standard |

**Support assembly dims:** 266 wide, 636 tall, 140 top section, 38 bottom extension. Top: 81+54+81 spacing.

### 5.0 Lever Assembly (Lever.iam)
| POS | QTY | Part Name | Specifications | Dimensions (mm) |
|-----|-----|---|---|---|
| 5.1 | 2 | Cover bracket | Thk 13 ASTM A36 | 138 x 64 x 13, 2x∅32 holes at 32 from edges |
| 5.2 | 1 | Barrette | OD 32 DIN C45 | ∅32 rod, 240 long, 16 dia at R3 grooves, 8 end stub |
| 5.3 | 1 | Barrette 1 | OD 32 DIN C45 | ∅32 rod, 170 long, R3 grooves, 8 end stub |
| 5.4 | 1 | Barrette 2 | OD 12 DIN C45 | ∅12 rod, 95 long, 8 between holes, 9 dia at grooves |
| 5.5 | 2 | Support barrette | OD 52 DIN C45 | ∅50 OD / ∅32 ID, 32 long (tube/bushing) |
| 5.6 | 2 | Side lever | Thk 6 ASTM A36 | 142 x 32 x 6, 135° bend, ∅13 hole at 16 from end |
| 5.7 | 1 | Side lever 1 | Thk 6 ASTM A36 | 90 x 51 x 6 |
| 5.8 | 2 | Cover lever | 50x50x6 ASTM A36 (angle) | 230 long, ∅32 hole at 32 from end, 21 from edge |
| 5.9 | 1 | Bar lever | OD 44 DIN C45 | ∅44 solid rod, 450 long (handle) |
| 5.10 | 6 | Cotter pins lever | DIN EN ISO 1234 | Standard |

**Lever assembly dims:** 532 tall, 356 lower section, 64 bracket zone, 142 width, 240 barrette, 22 gap.

### 6.0 Fixing Support / Platform (Fixing Support.iam)
| POS | QTY | Part Name | Specifications | Dimensions (mm) |
|-----|-----|---|---|---|
| 6.1 | 1 | Platform | Kiln dried wood | 2000 x 268 x 70, 2x∅25 holes, 4x∅16 holes, 106 thick cross-section |
| 6.2 | 3 | Platform base | Kiln dried wood | 400 x 152 x 51, 2x∅6 holes at 150 from end, 76 from bottom |
| 6.3 | 2 | Flat | Thk 10 ASTM A36 | 152 x 52 x 10, 2x∅16 holes at 32 from edge, 26 from bottom |
| 6.4 | 6 | Wood screw | GOST 1145-80 6x80 | Standard |

**Platform assembly dims:** 2000 long, 400 wide, 121 tall (with base), 780 press mounting zone, 924+924 symmetry, 300 base depth, 806 hole spacing on platform, 1083 offset.

---

## Technical Notes

### Metal Structure Treatment
- Paint iron structures to prevent rust
- Remove loose rust with wire brush, sandpaper, or chemical rust remover
- Sand chipping paint areas until smooth
- Remove dust/oil with degreaser or denatured alcohol
- Prime surface to protect against rust and corrosion

### Wood Treatment
- Treat wood with pesticides and kiln-dry for adequate humidity
- Apply wood sealer for later use

---

## Materials Summary

| Material | Parts |
|---|---|
| ASTM A36 Plate 13mm | Side(2), Base structure, Top support(2), Bottom top 1, Support piston(2), Support piston 1(2), Bar support(2), Internal support(2), Cover bracket(2) |
| ASTM A36 Plate 10mm | Base structure, Top, Piston top, Piston caps(2), Piston caps 1(2), Flat(2) |
| ASTM A36 Plate 6mm | Cap insurance 1, Side lever(2), Side lever 1 |
| ASTM A36 Angle 50x50x6 | Cover lever(2) |
| ASTM A36 C-channel 152x52x8 | Beam 1, Beam 2 |
| DIN C45 Rod ∅60 | Bars structure(2) |
| DIN C45 Rod ∅44 | Cap insurance, Bar lever |
| DIN C45 Tube ∅70/∅60 | Piston rod(2) |
| DIN C45 Tube ∅44/∅32 | Piston rod 1, Cap insurance |
| DIN C45 Rod ∅32 | Bottom top, Axis support, Barrette, Barrette 1 |
| DIN C45 Tube ∅50/∅32 | Support barrette(2) |
| DIN C45 Tube ∅40/∅20 | Support structure(2) |
| DIN C45 Rod ∅20 | Support structure 1 |
| DIN C45 Rod ∅12 | Barrette 2 |
| Kiln dried wood | Platform, Platform base(3) |

---

## Downloaded Files

### PDFs (ceta-ram/pdf/)
- `Cta_bmc_..._1.0.pdf` — Complete 53-page drawing set
- `Cta_bmc_..._A1.pdf` — 3D views
- `Cta_bmc_..._A2.pdf` — Exploded view
- `Cta_bmc_..._B1.pdf` — Parts list
- `Cta_bmc_..._C1.pdf` — Technical notes
- `Cta_bmc_..._1.0_.pdf` — Structure assembly
- `Cta_bmc_..._1.1.pdf` — Side part

### CAD Files (ceta-ram/cad/)
- `CAD-files/Cad/` — Autodesk Inventor .ipt (parts) and .iam (assemblies)
- `DWG-files/` — AutoCAD .dwg drawings for every part/assembly
- `STP-files/Stp/` — STEP files for each sub-assembly (importable to FreeCAD/OpenSCAD)

### Images (ceta-ram/images/)
- 13 photos/renders of the assembled machine

### Parametric Models
- `ceta_ram.scad` — OpenSCAD model, metric (mm), all 6 assemblies, lever_angle parameter
- `ceta_ram_imperial.scad` — OpenSCAD model, imperial (inches), standard US steel sizes
- `ceta_ram_imperial.py` — FreeCAD Python macro, imperial, builds 47 parts parametrically
- `CETA_RAM_Imperial.FCStd` — Pre-built FreeCAD file, open directly in FreeCAD GUI

### Imperial Conversion Notes
All metric steel sizes have been mapped to the nearest standard US imperial equivalent.
Rod/tube OD/ID pairs are matched so pins fit through bushings (e.g., 1-1/4" rod in
1-1/2" OD tube). Plate thicknesses: 13mm→1/2", 10mm→3/8", 6mm→1/4". C-channel:
152x52x8→C6x8.2. Bolts: M12/M14→1/2"-13. Brick size: 12" x 6" x ~4".

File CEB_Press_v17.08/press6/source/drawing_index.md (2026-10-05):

# CEB Press 6 — Drawing Cross-Reference Index

Maps the three documentation sources to each other:
- **2D set / BOM / A-Z manual** (2011-12): part numbers `01-XXX-00-X`, plate parts `L-XX` cut from the DXF libraries
- **Weldment set** (2015 redraw, ASME Y14.5): drawing numbers `001-0XXX` — same numeric lineage, formalized materials
- **DXF libraries**: CNC cut files by plate thickness (eighth/quarter/half inch)

| Part | BOM description (2011 set) | Weldment dwg (2015) | Weldment desc | Weldment material | In DXF lib |
|---|---|---|---|---|---|
| 01-000 |  |  |  |  |  |
| 01-001 |  |  |  |  |  |
| 01-002 | SUBASSEMBLY | 001-0002 | Frame Foot |  |  |
| 01-003 | SUBASSEMBLY | 001-0003 | Secondary Arm |  |  |
| 01-004 | L-A3 | 001-0004 | Angle, Secondary | ANGLE, STEEL, L6X4X1/2, OSE 4.1.1 | half |
| 01-005 |  | 001-0005 | Leg Holder |  |  |
| 01-006 | L-O6 | 001-0006 | Plate, Foot | FLAT BAR, STEEL, FB1/4X8, OSE 4.1.1 |  |
| 01-007 |  | 001-0007 | Leg | SQUARE TUBE, STEEL, HSS2X2X1/4, OSE 4.1. |  |
| 01-008 |  | 001-0008 | Leg Support Tube | SQUARE TUBE, STEEL, HSS2-1/2X2-1/2X3/16, |  |
| 01-009 | L-A2 | 001-0009 | Angle, Primary | ANGLE, STEEL, L6X4X1/2, OSE 4.1.1 | half |
| 01-010 | L-A1 | 001-0010 | Angle, Primary | ANGLE, STEEL, L6X4X1/2, OSE 4.1.1 |  |
| 01-011 |  | 001-0011 | Channel, Frame | CHANNEL, C6X13, STEEL, OSE 4.1.1 |  |
| 01-012 |  | 001-0012 | Plate | FLAT BAR, STEEL, FB3/8X3, OSE 4.1.1 |  |
| 01-014 | L-F1 | 001-0014 | Channel, Frame | CHANNEL, C6X13, STEEL, OSE 4.1.1 |  |
| 01-018 | SUBASSEMBLY |  |  |  |  |
| 01-019 | SUBASSEMBLY |  |  |  |  |
| 01-025 | L-D5 | 001-0025 | Plate Press | FLAT BAR, STEEL, FB1X7, OSE 4.1.1 | half |
| 01-026 | SUBASSEMBLY |  |  |  |  |
| 01-028 | L-D7 | 001-0028 | Plate | FLAT BAR, STEEL, FB1/2X3, OSE 4.1.1 |  |
| 01-029 | L-D3 | 001-0029 | Plate | FLAT BAR, STEEL, FB1/2X6, OSE 4.1.1 | half |
| 01-030 | L-D2 | 001-0030 | Plate | FLAT BAR, STEEL, FB1/4X7, OSE 4.1.1 | half |
| 01-032 | L-D1 | 001-0032 | Plate | FLAT BAR, STEEL, FB1/4X8, OSE 4.1.1 | half |
| 01-034 | L-F12 | 001-0034 | Channel, Frame | CHANNEL, C6X13, STEEL, OSE 4.1.1 |  |
| 01-035 | 1 X 5 STEEL FLAT BAR X 10 PER DETAIL | 001-0035 | Press Foot - Lower | FLAT BAR, STEEL, FB1X4, OSE 4.1.1 |  |
| 01-039 | SUBASSEMBLY |  |  |  |  |
| 01-041 | L-F2 | 001-0041 | Channel, Main | CHANNEL, C6X13, STEEL, OSE 4.1.1 |  |
| 01-042 | L-O2 | 001-0042 | Angle | ANGLE, L4X4X1/2, STEEL, OSE 4.1.1 |  |
| 01-044 | 1 X 2 STEEL FLAT X 5 PER DETAIL |  |  |  |  |
| 01-045 | 1 X 2 STEEL FLAT X 3 | 001-0045 | Plate, Hammer | FLAT BAR, STEEL, FB1X2, OSE 4.1.1 |  |
| 01-046 | 1IN CR FLAT BAR X 7-1/4 PER DETAIL | 001-0046 | Rod, Shaker Motor | ROUND BAR, STEEL, RB1, OSE 4.1.1 |  |
| 01-048 | SUBASSEMBLY | 001-0048 | Soil Shaker |  |  |
| 01-049 | 1/4 X 2 HR SQUARE TUBE X 43 | 001-0049 | Square Tubing, | SQUARE TUBE, STEEL, HSS2X2X1/4, OSE 4.1. |  |
| 01-051 | L-O1 | 001-0051 | Plate, Valve | FLAT BAR, STEEL, FB1/4X6, OSE 4.1.1 |  |
| 01-060 | L-H2 | 001-0060 | Plate, Hopper, | 11 GAUGE STEEL SHEET, OSE 4.1 | half/eighth |
| 01-061 | L-H3 | 001-0061 | Plate, Hopper, | 11 GAUGE STEEL SHEET, OSE 4.1 | eighth |
| 01-062 | L-H1 | 001-0062 | Plate, Hopper, | 11 GAUGE STEEL | half/eighth |
| 01-063 | SUBASSEMBLY |  |  |  |  |
| 01-066 | MCMASTER 15665A618 PIANO HINGE |  |  |  |  |
| 01-068 | 1/4 X 2 X 2 HR FLAT X 72 PER DETAIL |  |  |  |  |
| 01-069 | 1/4 X 2 X 2 HR ANGLE X 26-1/2 PER DETAIL | 001-0069 | Angle | ANGLE, STEEL, L2X2X1/4, OSE 4.1.1 |  |
| 01-070 | SUBASSEMBLY | 001-0070 | Heavy Hex Nut, |  |  |
| 01-071 | 1/4 X 2 HR FLAT BAR X 25 | 001-0071 | Rod, Grate | ROUND BAR, STEEL, RB1/2, OSE 4.1.1 |  |
| 01-074 | L-H6 |  |  |  |  |
| 01-076 | SUBASSEMBLY |  |  |  |  |
| 01-077 | SUBASSEMBLY | 001-0077 | Hammer, Shaker |  |  |
| 01-078 | SURPLUS CENTER 1-205-16-P-C |  |  |  |  |
| 01-079 | L-H9 |  |  |  | eighth |
| 01-080 | L-H8 |  |  |  | eighth |
| 01-081 | L-Q6 | 001-0081 | Plate | FLAT BAR, STEEL, FB1/4X6, OSE 4.1.1 | quarter |
| 01-082 | L-Q8 | 001-0082 | Plate | FLAT BAR, STEEL, FB1/4X2, OSE 4.1.1 | quarter |
| 01-083 | L-Q7 | 001-0083 | Plate | FLAT BAR, STEEL, FB1/4X3, OSE 4.1.1 | quarter |
| 01-084 | SUBASSEMBLY | 001-0084 | Electrical Box |  |  |
| 01-085 | surplus center 1-1563-E shaft coupler |  |  |  |  |
| 01-086 | 1/4 X 2 X 2 HR ANGLE X 72 PER DETAIL | 001-0086 | Angle | ANGLE, STEEL, L2X2X1/4, OSE 4.1.1 |  |
| 01-102 | MCMASTER-97245A521 CLEVIS PIN |  |  |  |  |
| 01-103 | 1-1/2 CR ROUND BAR X 11 PER DETAIL |  |  |  |  |
| 01-107 | L-F7 |  |  |  |  |
| 01-109 | 1/4 X 2" O.D. DOM TUBE X 1-1/2  | 001-0109 | Tube, Cylinder | TUBE, STEEL, DOM 2" OD X 1.5" ID, OSE 4. |  |
| 01-114 | SUBASSEMBLY | 001-0114 | Frame Weldment |  |  |
| 01-115 | L-F4 |  |  |  |  |
| 01-118 | 1/4 X 2 HR FLAT X 64-1/4 | 001-0118 | Flat, Grate | FLAT BAR, STEEL, FB1/4X2, OSE 4.1.1 |  |
| 01-119 | SUBASSEMBLY |  |  |  |  |
| 01-120 | L-F3 | 001-0120 | Roundstock, 1.5" | ROUND BAR, STEEL, RB1-1/2, OSE 4.1.1 |  |
| 01-121 | SUBASSEMBLY | 001-0121 | Spacer | FLAT BAR, STEEL, FB3/8X3, OSE 4.1.1 |  |
| 01-122 | L-F9 |  |  |  |  |
| 01-123 | L-F10 |  |  |  |  |
| 01-124 | L-F6 |  |  |  |  |
| 01-125 | L-F11 |  |  |  |  |
| 01-126 | L-F8 1/2" |  |  |  |  |
| 01-127 | SUBASSEMBLY |  |  |  |  |
| 01-128 | L-Q5 |  |  |  |  |
| 01-129 | L-Q3 |  |  |  | quarter |
| 01-130 | L-Q4 |  |  |  | quarter |
| 01-131 | L-F5 |  |  |  |  |
| 01-132 | L-D4 |  |  |  |  |
| 01-133 | L-D8 |  |  |  |  |
| 01-134 | L-D6 |  |  |  | half |
| 01-138 | L-A5 |  |  |  | half |
| 01-139 | L-A4 |  |  |  | half |
| 01-140 | SUBASSEMBLY |  |  |  |  |
| 01-141 | L-O9 |  |  |  |  |
| 01-142 | L-O10 |  |  |  |  |
| 01-143 | L-O11 |  |  |  |  |
| 01-144 | L-O3 |  |  |  | half |
| 01-145 | L-O4 |  |  |  | half |
| 01-146 | L-O5 |  |  |  | half |
| 01-149 | SUBASSEMBLY |  |  |  |  |
| 01-151 | L-H4 |  |  |  | eighth |
| 01-152 | L-H5 |  |  |  | eighth |
| 01-153 | SUBASSEMBLY |  |  |  |  |
| 01-154 | 1/4 X 2 X 2 ANGLE X 72 PER DETAIL |  |  |  |  |
| 01-155 | 3/16 X 2 HR SQUARE TUBE X 36 |  |  |  |  |
| 01-156 | SUBASSEMBLY |  |  |  |  |
| 01-157 | SUBASSEMBLY |  |  |  |  |
| 01-158 | 3/4 ROUND BAR X 5 PER DETAIL |  |  |  |  |
| 01-159 | SUBASSEMBLY |  |  |  |  |
| 01-161 | 3/4 X 4-1/4 ROUND TUBE X 2 PER DETAIL |  |  |  |  |
| 01-162 | 1 X 6 X 12 PLATE PREFERABLY AR300 PER DETAIL |  |  |  |  |
| 01-166 | 3/4 THREADED ROD X 3 |  |  |  |  |
| 01-169 | SUBASSEMBLY |  |  |  |  |
| 01-170 | SUBASSEMBLY |  |  |  |  |
| 01-171 | L-Q2 |  |  |  | quarter |
| 01-172 | L-Q1 |  |  |  | quarter |
| 01-173 | SUBASSEMBLY |  |  |  |  |
| 01-174 | SUBASSEMBLY |  |  |  |  |
| 01-175 | SUBASSEMBLY |  |  |  |  |
| 01-176 | SUBASSEMBLY |  |  |  |  |
| 01-177 | L-O16 |  |  |  |  |
| 01-178 | L-Q9 |  |  |  |  |
| 01-179 | L-O15 |  |  |  |  |
| 01-182 | 3/16 X 2-1/2 HR SQUARE TUBE X 6 PER DETAIL |  |  |  |  |
| 01-183 | SUBASSEMBLY |  |  |  |  |
| 01-184 | MCMASTER CARR 15665A604  |  |  |  |  |
| 01-185 | HYDRAULIC CYLINDER 25TL14-112 |  |  |  |  |
| 01-186 | 3/16 X 2 HR SQUARE TUBE X 38 PER DETAIL |  |  |  |  |
| 01-187 | PRESS CYLINDER CHIEF 216-380 |  |  |  |  |
| 01-188 | SUBASSEMBLY |  |  |  |  |
| 01-189 | 1/4 X 2-1/2 ROUND TUBE X 5-7/8 |  |  |  |  |
| 01-190 | SUBASSEMBLY |  |  |  |  |
| 01-191 | SURPLUS CENTER 9-7077-50 https://www.surplusc |  |  |  |  |
| 01-192 | L-F13 |  |  |  |  |
| 01-193 | MCMASTER 8739K74 - WEAR RESISTANT ACETAL |  |  |  |  |
| 01-194 | L-F14 |  |  |  |  |
| 01-195 | L-F15 |  |  |  |  |
| 01-196 | L-F16 |  |  |  |  |
| 01-199 | (14GA APROX.) SHEET METAL BACKING FOR PLASTIC |  |  |  |  |
| 01-220 | SUBASSEMBLY |  |  |  |  |
| 01-221 | 1IN CR ROUND BAR X 48IN LONG, PREFERABLY HIGH |  |  |  |  |
| 01-222 | PRINTED PLASTIC |  |  |  |  |
| 01-230 | PLASTIC PRINTED PER STL FILE |  |  |  |  |
| 01-231 | PLASTIC PRINTED PER STL FILE |  |  |  |  |
| 01-233 | MCMASTER 629K428 MDS FILLED NYLON BUSHING |  |  |  |  |
| 01-234 | MCMASTER 91663A590 RETAINING RING |  |  |  |  |

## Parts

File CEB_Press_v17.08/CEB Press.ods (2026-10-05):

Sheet: Tools & Materials
Category | Name | Unit Cost | Quantity | Total Cost | Source | Notes
 |  |  |  | $0.00
4 | 5" x 12" x 2.5" Crosstube Hydraulic Cylinder |  | 1 | $495.00 | https://www.surpluscenter.com/item.asp?item=9-1143-12&catname=hydraulic
4 | Solenoid Valve for rams Type C, Dalton Part #: 240-244 | 187 | 2 | $374.00 | http://stores.daltonhydraulic.com/-strse-674/Solenoid-Directional-Control-Valve%2C/Detail.bok | Max PSI 3600 | MAX GPPM 25
4 | 4"A x 6"B x 0.5"T |  | 288" | $313.20
4 | Daman Manifold AD05S033S or Dalton part# 240-712 (http://www.daltonhydraulic.com/d05-series-solenoid-valve-manifold-ad05-s-033-s) |  | 1 | $240.00 | http://stores.daltonhydraulic.com/StoreFront.bok
4 | 6", 13# |  | 274" | $238.00
4 | .25x2x2 |  | 288 | $210.00
 | 1/8"x5'x10' |  |  | $200.00
4 | Solenoid Valve for motor Type H, Dalton Part #: 240-241 |  | 1 | $172.00 | http://stores.daltonhydraulic.com/-strse-675/Solenoid-Directional-Control-Valve%2C/Detail.bok
3 | Labour and Tax |  |  | $170.00
3 | Dynamic Hydraulic Motor |  | 1 | $125.00 | https://www.surpluscenter.com/item.asp?item=9-7077-50&catname=hydraulic
4 | 6x12 (optional for jig) |  | 50 | $122.00
4 | 2.5" x 14" x 1.125" Clevis |  | 1 | $94.00 | https://www.surpluscenter.com/item.asp?catname=hydraulic&qty=1&item=9-7619-14
4 | 1/2" Flow Control and Relief Valve |  | 1 | $87.00 | https://www.surpluscenter.com/item.asp?item=9-064-50&catname=hydraulic
5 | 1/2"NPTF | 17 | 5 | $85.00 | https://www.surpluscenter.com/item.asp?item=928&catname=hydraulic
4 | .5x6x6 |  | 12 | $67.00
4 | .125x3 |  | 288 | $66.00
3 | Welding Wire, Torching Gas, Welding Gas |  |  | $60.00
3 | V-Groove Bearing | 15 | 4 | $60.00 | http://www.vxb.com/page/bearings/PROD/Kit8406
4 | 2"A x 2"B x 0.25"T |  | 291" | $58.20
4 | .1875x2.5x2.5 |  | 84 | $58.00
4 | .5x3 |  | 93.5 | $50.00
4 | 4"A x 4"B x 0.5"T |  | 105" | $46.00
3 | DOM Round 1.5" |  | 14.5" | $40.00
 | 1/8"x5'x23.5" |  |  | $40.00
4 | .25x8 |  | 44.5 | $38.00
4 | 1x7 |  | 12 | $37.00
4 | 1/2"x96" NPTM | 18 | 2 | $36.00 | https://www.surpluscenter.com/item.asp?item=905-1296&catname=hydraulic
4 | 0.5, 20' long | 7 | 5 | $35.00
3 | Outdoor Main Lug Box |  | 1 | $33.00 | Hardware Store | http://opensourceecology.org/wiki/File:LugBox.png
4 | 4"A x 7"B x 0.5"T |  | 12" | $32.00
3 | Rebar | 6 | 5 | $30.00
4 | 1/2"x36" NPTM | 10 | 3 | $30.00 | https://www.surpluscenter.com/item.asp?item=905-1236&catname=hydraulic
4 | 1/2" NPT Needle Valve |  | 1 | $29.00 | http://www.surpluscenter.com/item.asp?item=9-7960-8&catname=hydraulic
4 | .5x2 |  | 72 | $28.00
4 | 1x6 |  | 12 | $28.00
4 | .375x 3 |  | 51 | $27.00
4 | 1/2"x56" NPTM | 13 | 2 | $26.00 | https://www.surpluscenter.com/item.asp?item=905-1260&catname=hydraulic
5 | 3/4"NPTF |  | 1 | $26.00 | https://www.surpluscenter.com/item.asp?item=928-C&catname=hydraulic
5 | 0.75"-10x2"x2" | 0.49 | 53 | $25.97 | Mo-kan Fasteners
5 | SAE 6M to 1/2" | 4 | 6 | $24.00 | https://www.surpluscenter.com/item.asp?item=9-6900-6-8&catname=hydraulic
4 | .25x7 |  | 27 | $23.00
4 | .5x6 |  | 12 | $22.00
3 | Threaded Rod- .75" |  | 40.75" | $21.00
3 | Pillow Block Bearing - 1" | 10 | 2 | $20.00 | https://www.surpluscenter.com/item.asp?item=1-205-16-P-C&catname=powerTrans
4 | .1875x2.5 |  | 72 | $19.00
4 | 1x4 |  | 10 | $19.00
4 | 1/2" NPTF Check Valve |  | 1 | $17.00 | https://www.surpluscenter.com/item.asp?item=9-7933-8-5&catname=hydraulic
4 | 0.75"-10 | 0.18 | 89 | $16.02 | Mo-kan Fasteners
3 | Power Clamps 1" Max OD | 4 | 4 | $16.00 | Automotive Store | http://opensourceecology.org/wiki/File:Hose_Clamps.jpg
3 | 50ft 16AWG Extension Cord |  | 1 | $16.00 | Hardware Store | http://opensourceecology.org/wiki/File:50ft3Wire16AWGExtensionCord.jpg
3 | Gasoline |  |  | $15.00
3 | DOM Tubing 1.5"ID x 2"OD |  | 3" | $14.00
4 | Washer, Wide, 0.75" | 0.17 | 74 | $12.58 | Mo-kan Fasteners
4 | .25x6 |  | 27 | $12.00
3 | Generic Door Hinge | 1 | 12 | $12.00 | Home Depot
3 | 1" Keyed Coupler |  | 1 | $12.00 | https://www.surpluscenter.com/item.asp?item=1-1563-E&catname=powerTrans
4 | .25x2 |  | 71.5 | $11.00
4 | 1x2 |  | 11 | $11.00
5 | 1/2" NPT | 1.7 | 6 | $10.20 | https://www.surpluscenter.com/item.asp?item=9-5404-8-8&catname=hydraulic
4 | 1/2" NPTF Tee | 5 | 2 | $10.00 | https://www.surpluscenter.com/item.asp?item=9-5605-8-8-8&catname=hydraulic
5 | 1/2" NPTM to 1/2" NPTF | 3.2 | 3 | $9.60 | https://www.surpluscenter.com/item.asp?item=9-5502-8-8&catname=hydraulic
3 | DOM Round 1" |  | 7.25" | $9.00
4 | .25x3 |  | 6 | $7.00
5 | SAE 12M to 3/4" | 3.5 | 2 | $7.00 | https://www.surpluscenter.com/item.asp?catname=&qty=1&item=9-6900-12-12
3 | Fuse Holder |  | 1 | $7.00 | Hardware Store | http://opensourceecology.org/wiki/File:FuseHolder.jpg
4 | Copper Clad board 6" x 6" |  | 1 | $7.00 | http://search.digikey.com/us/en/products/509/473-1002-ND/559705 | 473-1002-ND
4 | Power N MOSFET | 1.3 | 5 | $6.50 | http://search.digikey.com/scripts/DkSearch/dksus.dll?Detail&name=RFD16N05LSM9ACT-ND | RFD16N05LSM9ACT-ND
4 | 3", 6# |  | 3" | $6.00
4 | .25x1 |  | 14 | $6.00
4 | 1" |  | 14" | $6.00
3 | 12cm by 7.5cm by 0.4cm HDPE Plate (4.75"x3"x5/32") | 3 | 2 | $6.00 | Hardware Store
5 | 1/2" NPTM | 2.9 | 2 | $5.80 | https://www.surpluscenter.com/item.asp?item=9-5500-8-8&catname=hydraulic
4 | 1/4"x12" NPTM |  | 1 | $5.00 | https://www.surpluscenter.com/item.asp?item=916-1412&catname=hydraulic
4 | Ring Insulated 10-12AWG | 0.25 | 20 | $5.00 | Hardware Store
3 | Toggle Switch |  | 1 | $5.00 | Hardware Store | http://opensourceecology.org/wiki/File:ToggleSwitch.jpg
5 | 3/4" to 1/2" NPT | 2.3 | 2 | $4.60 | https://www.surpluscenter.com/item.asp?item=9-5406-12-8&catname=hydraulic
4 | 2 Pos Terminal | 0.5 | 9 | $4.50 | http://search.digikey.com/scripts/DkSearch/dksus.dll?vendor=0&keywords=ED1514-ND | ED1514-ND
5 | 0.75"-10x1.5"x1.5" | 0.49 | 9 | $4.41 | Mo-kan Fasteners
4 | Green LED | 0.6 | 7 | $4.20 | http://search.digikey.com/scripts/DkSearch/dksus.dll?Detail&name=160-1169-1-ND | 160-1169-1-ND
4 | 1x1 |  | 5 | $3.00
3 | 12mm x 3mm N42 Epoxy Coated Disc Magnet | 0.5 | 6 | $3.00 | http://www.gaussboys.com/ndfeb-magnets/D1203E-N42.html
3 | Pair of Large Alligator Clips (Black and Red) |  | 1 | $3.00 | Hardware Store | http://opensourceecology.org/wiki/File:AlligatorClips.jpg
4 | Diode | 0.6 | 5 | $3.00 | http://search.digikey.com/scripts/DkSearch/dksus.dll?Detail&name=641-1331-1-ND | 641-1331-1-ND
5 | 0.75"-10x2.5"x2.5" | 0.49 | 6 | $2.94 | Mo-kan Fasteners
5 | 0.75"-10x3"x3" | 0.49 | 6 | $2.94 | Mo-kan Fasteners
5 | 1/2" NPT to 3/8" NPT | 1.4 | 2 | $2.80 | http://www.surpluscenter.com/item.asp?item=9-5406-8-6&catname=hydraulic
5 | 0.5"-13x1"x1" | 0.17 | 16 | $2.72 | Mo-kan Fasteners
4 | 0.375, 2' long | 2 | 1 | $2.00
4 | M12, 55mm | 0.5 | 4 | $2.00 | Mo-kan Fasteners
4 | 8 Pos Header | 0.9 | 8 | $1.80 | http://search.digikey.com/scripts/dksearch/dksus.dll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 | A1914-ND
5 | SAE 4M to 1/4" NPTF |  | 1 | $1.50 | https://www.surpluscenter.com/item.asp?item=9-6900-4-4-S&catname=hydraulic
5 | 1/2" NPTM to 1/4" NPTF |  | 1 | $1.50 | https://www.surpluscenter.com/item.asp?item=9-5406-8-4&catname=hydraulic
4 | 499 Resistor | 0.3 | 5 | $1.50 | http://search.digikey.com/scripts/DkSearch/dksus.dll?Detail&name=311-499FRCT-ND | 311-499FRCT-ND
4 | 49.9k Resistor | 0.3 | 5 | $1.50 | http://search.digikey.com/scripts/DkSearch/dksus.dll?Detail&name=311-49.9KFRCT-ND | 311-49.9KFRCT-ND
4 | 0.5"-13 | 0.06 | 24 | $1.44 | Mo-kan Fasteners
4 | Washer, Wide, 0.5" | 0.05 | 28 | $1.40 | Mo-kan Fasteners
4 | 6 Pos Header | 0.7 | 2 | $1.40 | http://search.digikey.com/scripts/DkSearch/dksus.dll?vendor=0&keywords=a1913-nd | A1913-ND
5 | 0.313"-18x0.625"x0.625" | 0.17 | 8 | $1.36 | Mo-kan Fasteners
5 | 3/8" NPT | 0.6 | 2 | $1.20 | http://www.surpluscenter.com/item.asp?item=9-7184&catname=hydraulic
3 | Wire Clamps | 0.5 | 2 | $1.00 | Hardware Store | http://opensourceecology.org/wiki/File:WireClamps.jpg
4 | Ring Insulated 14-16AWG | 0.25 | 4 | $1.00 | Hardware Store
3 | Buss Fuse 10Amp |  | 1 | $1.00 | Hardware Store | http://opensourceecology.org/wiki/File:10ABussFuse.jpg
4 | reset switch |  | 1 | $1.00 | http://search.digikey.com/scripts/DkSearch/dksus.dll?Detail&name=SW262CT-ND | SW262CT-ND
5 | 0.5"-13x2"x1.25" | 0.17 | 5 | $0.85 | Mo-kan Fasteners
4 | B18.2.4.1M, Style 1, M12 x | 0.18 | 4 | $0.72 | Mo-kan Fasteners
4 | 0.375"-16 | 0.18 | 4 | $0.72 | Mo-kan Fasteners
5 | 0.375"-16x2"x2" | 0.17 | 4 | $0.68 | Mo-kan Fasteners
5 | 0.25"-14x2" | 0.17 | 4 | $0.68 | Mo-kan Fasteners
4 | Plain, Narrow, B18.22.M, | 0.17 | 4 | $0.68 | Mo-kan Fasteners
4 | 10k Resistor | 0.3 | 2 | $0.60 | http://search.digikey.com/scripts/DkSearch/dksus.dll?Detail&name=311-10.0KFRCT-ND | 311-10.0KFRCT-ND
4 | 100 Resistor | 0.3 | 2 | $0.60 | http://search.digikey.com/us/en/products/RC1206FR-07100RL/311-100FRCT-ND/731438 | 311-100FRCT-ND
4 | Ring Insulated Small Hole 10-12AWG | 0.25 | 2 | $0.50 | Hardware Store
3 | Washer 1.25" OD .5" ID | 0.25 | 2 | $0.50 | Hardware Store | http://opensourceecology.org/wiki/File:Washer1-25OD0-5ID.jpg
4 | Washer, Wide, 0.375" | 0.05 | 8 | $0.40 | Mo-kan Fasteners
5 | 0.5"-13x4"x4" | 0.17 | 2 | $0.34 | Mo-kan Fasteners
4 | Female Insulated 16-22AWG |  | 1 | $0.25 | Hardware Store
4 | Male Insulated 10-12AWG |  | 1 | $0.25 | Hardware Store
4 | .25"-16, Lock | 0.18 | 1 | $0.18 | Mo-kan Fasteners
4 | Washer, Lock, 0.25" | 0.05 | 1 | $0.05 | Mo-kan Fasteners
1 | Tools
 |  |  |  | $4,433.78
1 | Materials
2 | Steel
3 | Angle
3 | C Channel
3 | Flat (all measurements in ")
3 | Tubing
3 | sheet
2 | Hydraulics
3 | Cylinders
3 | Hoses
3 | Valves
3 | Fittings
4 | Swivel
4 | Hex Nipple
4 | Bushing
4 | 90Deg Elbow
4 | Quick Coupler Pair
3 | Solenoid
2 | Other
2 | Fasteners
3 | Bolt
4 | HHCS
3 | Hex Nut
3 | Washer
2 | Electronics
3 | Connectors |  |  |  | Hardware Store
3 | Fasteners
4 | Machine Screws
5 | M3 20mm | 1 | 4 |  | Hardware Store
5 | 8-32, 3/8 inch length | 6.11 | 7 |  | Hardware Store
5 | 8-32, ¾ inch length | 25.58 | 4 |  | Hardware Store
4 | M3 Nylon-threaded Locknuts | 3.81 | 4 |  | Hardware Store
3 | Arduino Uno Microcontroller | 19.99 | 1 |  | http://www.digikey.com/1/parts/2412553-arduino-uno-board-a000046.html
3 | Underground Telephone Wire (4-wire) | 6.12 | 3m |  | Hardware Store
3 | Shrink Tubing 16-22AWG 18cm length | ? | 1 |  | Hardware Store
3 | Hall Effect Sensor | 155 | 2 |  | http://www.sparkfun.com/products/9312
3 | PVC Pipe with 1" Outer Diameter, 9/16" Inner Diameter, 3.5" Length | ? | 2 |  | Hardware Store
3 | Silicone | 39.99 | 250ml |  | Hardware Store | Transparent Caulking
3 | Red Wire 18AWG |  | 25Ft |  | Hardware Store
3 | Black Wire 18AWG |  | 25Ft |  | Hardware Store
3 | Solenoid Driver
 |  |  |  | $8,867.56

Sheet: Final Cut List
Final Cut list : Steel
StockSize | Size (Inches) | Length (Inches) | QTY. | Primary Part Name | Secondary Part Name | Step # | ITEM NO. | PART NUMBER | Second Part Number
Angle | .25x2x2 | 6 | 2 | Main Frame | Dirt Blockers | 17 | 6.2 | 100107
 |  | 6 | 2 | Wide cylinder support |  | 12 | 6.21.1 | 100100
 |  | 10 | 2 | Soil Shaker | Side of guard | 3 | 10.1.5 | 100105
 |  | 16 | 2 | Soil Shaker | top and bottom of guard | 3 | 10.1.6 | 100106
 |  | 35.5 | 2 | Soil Grate |  | 9 | 21.2 | 100069
 |  | 72 | 2 | Soil Grate |  | 9 | 21.1,21.3 | 100,068 | 100,086
Angle | .5x4x4 | 8 | 1 | Soil Shaker |  | 3 | 10.1.2 | 100043
 |  | 21 | 1 | Soil Shaker |  | 3 | 10.1.1 | 100042
 |  | 38 | 2 | Grate supports |  | 6 | 22, 30 | 100073 | 100091
Angle | .5x4x6 | 72 | 2 | Secondary Arms |  | 2 | 3.2, 7.2.2 | 100004
 |  | 72 | 2 | Primary Arms |  | 2 | 4, 5 | 100009 | 100010
Angle | .5x4x7 | 12 | 1 | Soil Loading Drawer | Back | 10 | 9.3 | 100024
C-Channel | 3 | 1.5 | 2 | Main Frame Small Components | Thin Cylinder support | 13 | 6.26.1 | 100112
C-Channel | 6 heavy | 13 | 2 | Main Frame | Spacers | 17 | 6.4.3, 6.5.3 | 100034
 |  | 21 | 4 | Main Frame | Horizontal Members | 14 | 6.2.1, 6.3, 6.25.1 | 100014 | 100041
 |  | 29 | 2 | Wide cylinder support |  | 12 | 6.1.1 | 100011
 |  | 53 | 2 | Main Frame | Vertical Members | 14 | 6.4.1, 6.5.1 | 100115 | 100015
DOM Round | 1.5 | 3.5 | 1 | Main Cylinder | Fill in rod tubing | 16
 |  | 11 | 1 | Main Frame | Cylinder Pin | 18 | 6.24 | 100103
Dom tubing | 1.5 ID 2.0OD | 1.5 | 2 | Main Frame | Horizontal Members, cylinder mounting | 18 | 6.25.2 | 100109
Flat | .1875x2.5 | 36 | 2 | Soil Loading Drawer | Outer Rails | 10 | 9.1 | 100022
Flat | .25x1 | 14 | 1 | Main Frame Small Components | Magnet Holder | 13 | 6.22.1 | 100093
Flat | .25x2 | 12 | 1 | Controller Mount |  | 1 | 27.3 | 100082
 |  | 71.5 | 1 | Soil Grate | Cross piece | 9 | 21.6 | 100118
Flat | .25x3 | 6 | 1 | Controller Mount | Bottom piece | 1 | 27.1 | 100083
Flat | .25x6 | 12 | 1 | Valve Mount |  | 1 | 12 | 100051
 |  | 15 | 1 | Controller Mount |  | 1 | 27.2 | 100081
Flat | .25x7 | 13.5 | 2 | Soil Loading Drawer | Sides | 10 | 9.7 | 100030
Flat | .25x8 | 8 | 4 | Feet |  | 2 | 1.2 | 100006
Flat | .25x8 | 12.5 | 1 | Soil Loading Drawer | Roof | 10 | 9.9 | 100032
Flat | .375x 3 | 24 | 2 | Main Frame | Horizontal Members Reinforcement | 17 | 6.1.2 | 100012
 |  | 3 | 1 | Roller Guides | Spacer Plate | 11 | 6.11 | 100055
Flat | .5x2 | 36 | 2 | Soil Loading Drawer | Inner Rails | 10 | 9.2 | 100023
Flat | .5x3 | 3 | 1 | Secondary arms | Eye for 2nd cyl | a5 | 7.1 | 100017
 |  | 3 | 1 | Soil Loading Drawer | Tongue | 10 | 9.5 | 100028
 |  | 3 | 1 | Roller Guides | Spacer Plate | 11 | 6.11 | 100055
 |  | 11.25 | 2 | Hopper Mounting Plate |  | 8 | 13.2 | 100058
 |  | 15 | 2 | Hopper Mounting Plate |  | 8 | 13.1 | 100057
 |  | 16 | 2 | Roller Guides | Main Plate | 11 | 6.6.1 | 100020
Flat | .5x6 | 12 | 1 | Soil Loading Drawer | Vertical Supports | 10 | 9.6 | 100029 | 100064
Flat | 1/8x3 | 36 | 8 | Hopper Sheet Metal | Hinge Plates | 7 | 16.4, 16.5 | 100065
Flat | 1x1 | 2.5 | 2 | Preparing the Main Cylinder | Press foot supports | 16 | 6.9.3 | 100040
Flat | 1x2 | 5 | 1 | Soil Shaker | Hammer | 4 | 10.3.1 | 100044
 |  | 6 | 1 | Soil Shaker | Hammer | 4 | 10.3.2 | 100045
Flat | 1x4 | 10 | 1 | Preparing the Main Cylinder | Lower Press Foot | 15 | 6.9.2 | 100035
Flat | 1x6 | 12 | 1 | Preparing the Main Cylinder | Upper Press foot | 15 | 6.10.1 | 100036
Flat | 1x7 | 12 | 1 | Soil Loading Drawer | Press Plate | 10 | 9.4 | 100025
Pipe | .75ID 1OD | 1 | 2 | Main Frame Small Components | Thin Cylinder support | 13 | 6.26.2 | 100111
Rebar | 0.375 | 3 | 1 | Main Frame Small Components | Sensor Holder | 13 | 33.2 | 100099
 |  | 6 | 1 | Main Frame Small Components | Sensor Holder | 13 | 6.28.2 | 100096
Rebar | 0.5 | 34 | 33 | Soil Grate |  | 9 | 21.4 | 100071
Rebar | 1 | 7 | 2 | Soil Shaker |  | 3 | 10.1.3 | 100047
Round | 1 | 7.25 | 1 | Soil Shaker |  | 4 | 10.3.3 | 100046
Threaded Rod | 0.75 | 1.25 | 1 | Main Frame Small Components | Magnet Holder | 13 | 6.22.2 | TROD 0.7500-1x1.25
 |  | 3.5 | 1 | Main Frame Small Components | Sensor Holder | 13 | 6.28.1 | TROD 0.7500-1x3.5
 |  | 3.5 | 1 | Main Frame Small Components | Sensor Holder | 13 | 33.1 | TROD 0.7500-1x3.5
 |  | 6.25 | 2 | Main Frame Small Components | Thin Cylinder support | 13 | 6.27.1 | TROD 0.7500-1x6.25
 |  | 3.75 | 4 | Main Frame | Drawer member drawer adjuster bolts | 14
 |  | 2.5 | 2 | Main Cylinder | Upper Press foot | 15 | 6.10.2 | 100037
Tubing | .1875x2.5x2.5 | 6 | 14 | Leg Holders |  | 2 | 1.1.1, 3.1.1,6.2.2.1,7.2.1.1 | 100007
Tubing | .25x2x2 | 48 | 4 | Legs |  | 2 | 2 | 100008
 |  |  | 2 | Hopper Supports |  | 6 | 11.1 | 100049
Tubing | .5x6x6 | 12 | 1 | Soil Loading Drawer | Spacer | 10 | 9.8 | 100031
 | 6x12 | 50 | 1 | Optional Jig for Main Frame Assembly |  | 17
Sheet | See link for how to cut hopper, dirt keeper plate, brick holder plate, and soil shaker guard

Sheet: Sheet4
1544.8
19.9
12
13.3
108
57.5
14.9
22
23
8.9
32.9
54
11.5
56
49.5
104
20
17
27.5
45
119
35
22.5
21
115
59.5
52 | desodorante
79.5
39.9
25.5
99
46
15
32
20
55

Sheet: Parts Fabrication
Make Page Steel Requirements : Steel
Step | StockSize | Size (Inches) | Length (Inches) | QTY. | Part Name
1 | Flat | .25x2 | 12 | 1 | Controller Mount
1 | Flat | .25x3 | 6 | 1 | Controller Mount, Bottom Piece
1 | Flat | .25x6 | 12 | 1 | Valve Mount
1 | Flat | .25x6 | 15 | 1 | Controller Mount
1 | Sheet | .125x29x13.5 |  | 1 | Dirt Keeper Plate
1 | Sheet | .125x29x17.5 |  | 1 | Brick Holder Plate
2 | Angle | .5x4x6 | 72 | 2 | Secondary Arms
2 | Angle | .5x4x6 | 72 | 2 | Primary Arms
2 | Flat | .25x8 | 8 | 4 | Feet
2 | Tubing | .1875x2.5x2.5 | 6 | 14 | Leg Holders
2 | Tubing | .25x2x2 | 48 | 4 | Legs
3 | Angle | .25x2x2 | 10 | 2 | Sides of guard
3 | Angle | .25x2x2 | 16 | 2 | Top and bottom of guard
3 | Angle | .5x4x4 | 8 | 1 | Motor mount angle
3 | Angle | .5x4x4 | 21 | 1 | Hopper Mount Angle
3 | Rebar | 1 | 7 | 2 | Braces
3 | Sheet | .125x10x16 |  | 1 | Guard
4 | Flat | 1x2 | 5 | 1 | Hammer
4 | Flat | 1x2 | 6 | 1 | Hammer
4 | Round | 1 | 7.25 | 1 | Shaft
6 | Angle | .5x4x4 | 38 | 2 | Grate supports
6 | Tubing | .25x2x2 |  | 2 | Hopper Supports
7 | Flat | 1/8x3 | 36 | 8 | Hinge Plates
8 | Flat | .5x3 | 11.25 | 2 | Hopper Mounting Plate
8 | Flat | .5x3 | 15 | 2 | Hopper Mounting Plate
9 | Angle | .25x2x2 | 35.5 | 2 | Frame Short Pieces
9 | Angle | .25x2x2 | 72 | 2 | Frame Long Pieces
9 | Flat | .25x2 | 71.5 | 1 | Cross Support
9 | Rebar | 0.5 | 34 | 33 | Rebars
10 | Angle | .5x4x7 | 12 | 1 | Back
10 | Flat | .1875x2.5 | 36 | 2 | Outer Rails
10 | Flat | .25x7 | 13.5 | 2 | Sides
10 | Flat | .25x8 | 12.5 | 1 | Roof
10 | Flat | .5x2 | 36 | 2 | Inner Rails
10 | Flat | .5x3 | 3 | 1 | Tongue
10 | Flat | .5x6 | 12 | 1 | Vertical Supports
10 | Flat | 1x7 | 12 | 1 | Press Plate
10 | Tubing | .5x6x6 | 12 | 1 | Spacer
11 | Flat | .375x 3 | 3 | 1 | Spacer Plate
11 | Flat | .5x3 | 3 | 1 | Spacer Plate
11 | Flat | .5x3 | 16 | 2 | Main Plate
12 | Angle | .25x2x2 | 6 | 2 | Wide cylinder support Vertical
12 | C-Channel | 6 heavy | 29 | 2 | Wide cylinder support Horizontal
13 | C-Channel | 3 | 1.5 | 2 | Thin Cylinder support
13 | Flat | .25x1 | 14 | 1 | Magnet Holder
13 | Pipe | .75ID 1OD | 1 | 2 | Thin Cylinder support
13 | Rebar | 0.375 | 3 | 1 | Sensor Holder
13 | Rebar | 0.375 | 6 | 1 | Sensor Holder
13 | Threaded Rod | 0.75 | 1.25 | 1 | Magnet Holder
13 | Threaded Rod | 0.75 | 3.5 | 1 | Sensor Holder
13 | Threaded Rod | 0.75 | 3.5 | 1 | Sensor Holder
13 | Threaded Rod | 0.75 | 6.25 | 2 | Thin Cylinder support
14 | C-Channel | 6 heavy | 21 | 4 | Horizontal Members
14 | C-Channel | 6 heavy | 53 | 2 | Vertical Members
14 | Threaded Rod | 0.75 | 3.75 | 4 | Drawer member drawer adjuster bolts
15 | Flat | 1x4 | 10 | 1 | Lower Press Foot
15 | Flat | 1x6 | 12 | 1 | Upper Press foot
15 | Threaded Rod | 0.75 | 2.5 | 2 | Upper Press foot
16 | DOM Round | 1.5 | 3.5 | 1 | Fill in rod tubing
16 | Flat | 1x1 | 2.5 | 2 | Press foot supports
17 | Tubing | 6x12 | 50 | 1 | Optional Jig
17 | Angle | .25x2x2 | 6 | 2 | Dirt Blockers
17 | C-Channel | 6 heavy | 13 | 2 | Spacers
17 | Flat | .375x 3 | 24 | 2 | Horizontal Members Reinforcement
18 | DOM Round | 1.5 | 11 | 1 | Cylinder Pin
18 | Dom tubing | 1.5 ID 2.0OD | 1.5 | 2 | Horizontal Members, cylinder mounting
Assembly 5 | Flat | .5x3 | 3 | 1 | Eye for 2nd cyl

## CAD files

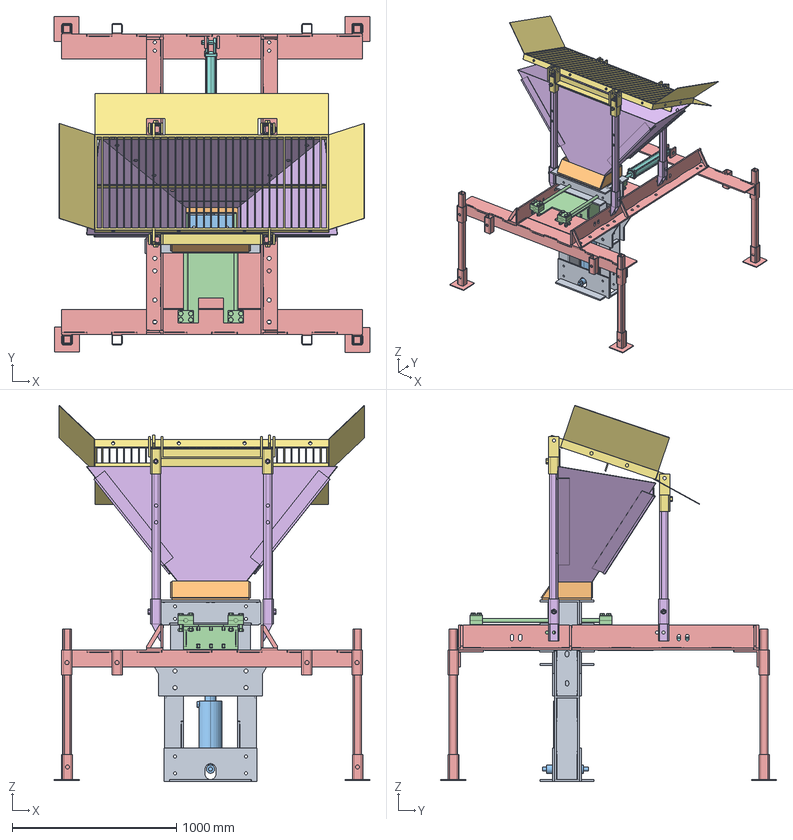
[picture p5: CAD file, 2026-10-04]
CEB_Press_v17.08/source/CEB_17.08_CAD_Assembly.fcstd
1920.9 x 2044.7 x 2290.9 mm
Frame_SubAssembly_01
Hopper_Seat_Subassembly_01
Cylinder_SubAssembly_01
Drawer_SubAssembly_01
Arms_Subassembly_01
Hopper_Subassembly_01
Crate_Subassembly_01
Cylinder_secondary_Subassembly_01

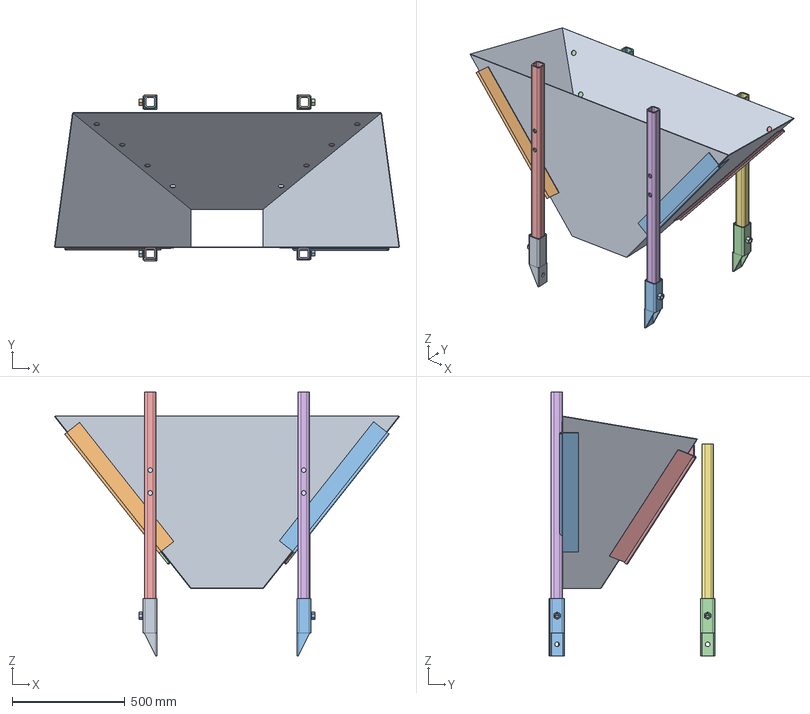
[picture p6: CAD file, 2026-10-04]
CEB_Press_v17.08/source/subassemblies/Hopper_Subassembly.fcstd
1529.0 x 733.7 x 1168.4 mm
Hopper_support_mount_module_01
Hopper_support_mount_module_01001
Hopper_support_mount_module_01002
Hopper_support_mount_module_01003
hopper_support_long_01
hopper_support_long_01001
hopper_support_short_01
hopper_support_short_01001
Hopper_sheet_module_01
hinch_01
hinch_02
hinch_03
hinch_04

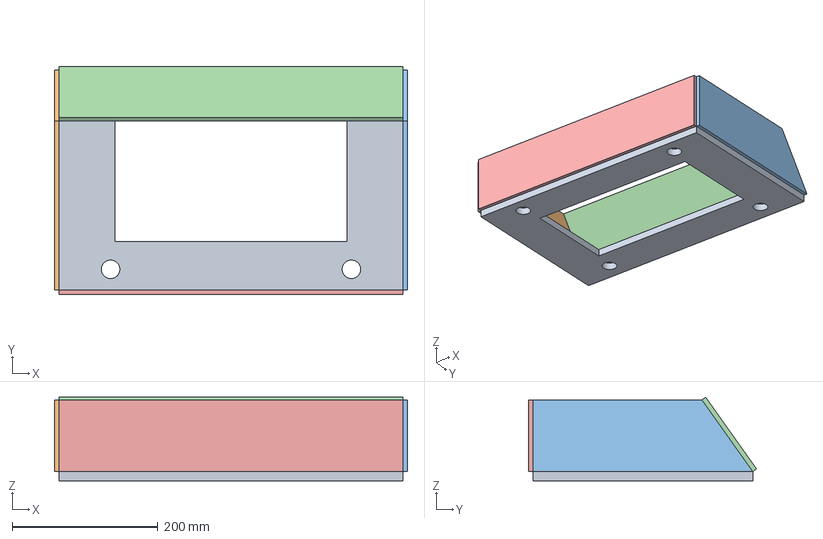
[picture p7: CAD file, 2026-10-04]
CEB_Press_v17.08/source/subassemblies/Hopper_Seat_Subassembly.fcstd
484.1 x 312.9 x 114.8 mm

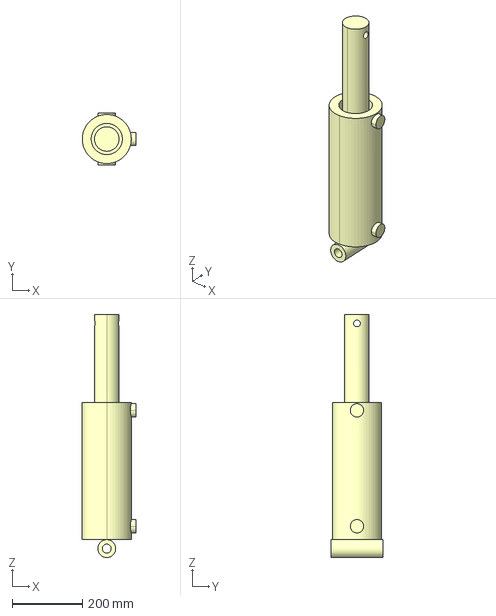
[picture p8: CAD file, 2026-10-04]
CEB_Press_v17.08/source/subassemblies/Cylinders/main_cylinder.fcstd
152.4 x 149.2 x 692.1 mm

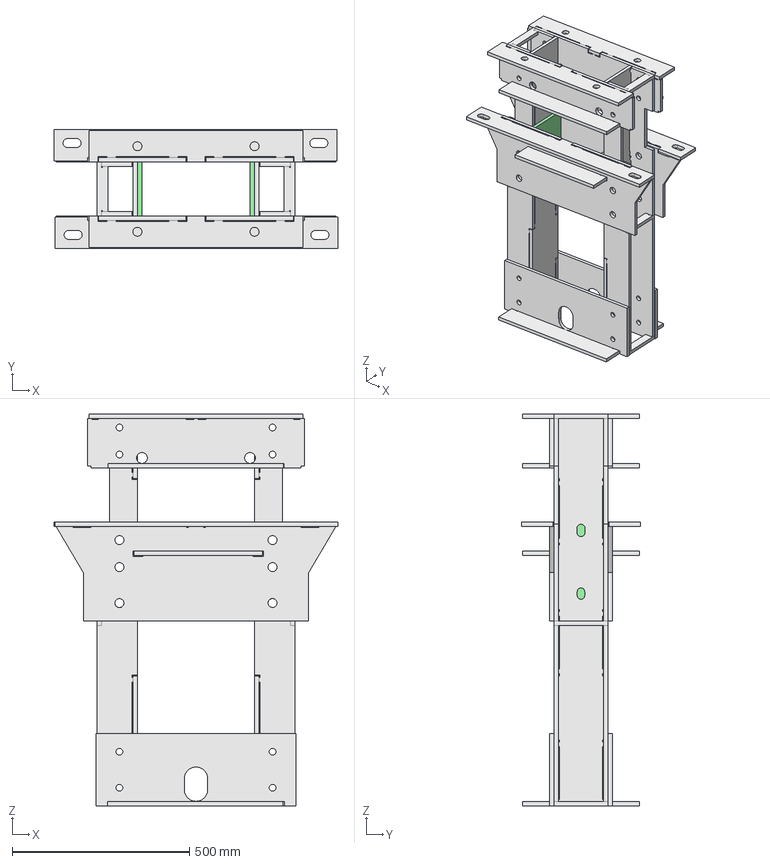
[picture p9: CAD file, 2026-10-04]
CEB_Press_v17.08/source/subassemblies/Frame_SubAssembly.fcstd
800.6 x 335.2 x 1105.5 mm
Main_Leg_Module_01
Main_Leg_Module_01001
Chamber_Spacer_01
Chamber_Spacer_01001
Top_Panel_Module_01
Top_Panel_Module_01001
Frame_bottom_module_01
Frame_bottom_module_02
Frame_middle_module_01
Frame_middle_module_02

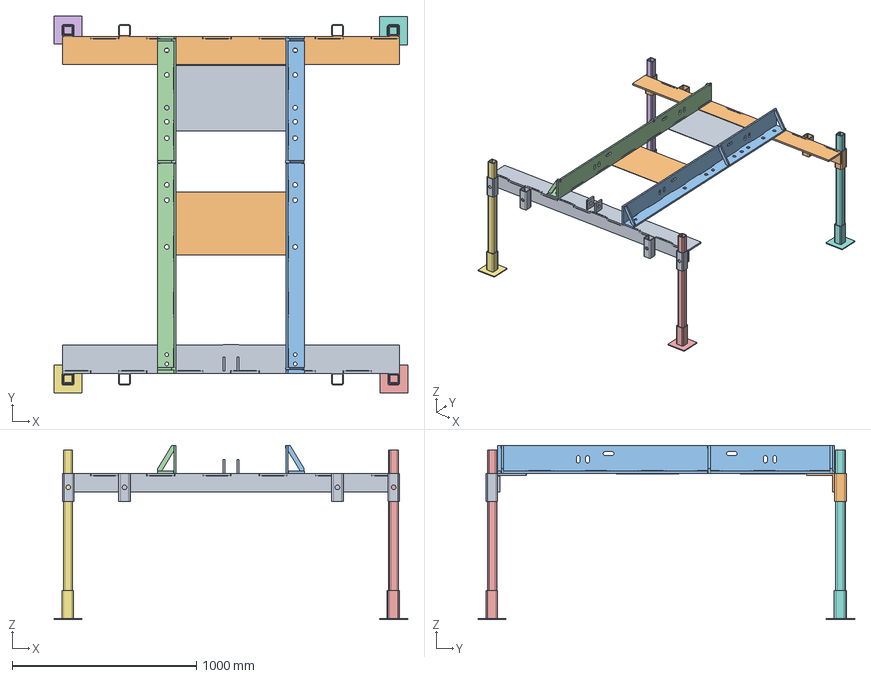
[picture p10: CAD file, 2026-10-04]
CEB_Press_v17.08/source/subassemblies/Arms_Subassembly.fcstd
1920.9 x 2044.7 x 945.3 mm
Arm_4_Module_01
Arm_3_Module_01
Arm_1_Module_01
Arm_2_Module_01
Leg_Module_01
Leg_Module_01001
Leg_Module_01002
Leg_Module_01003
Table_6048_01
Table_6049_01

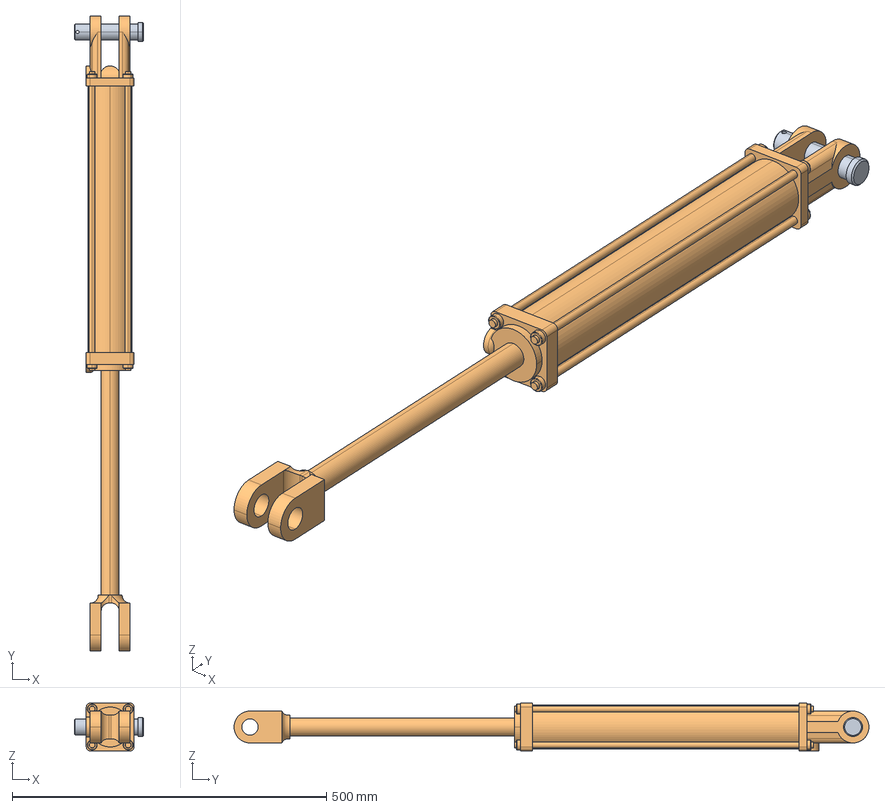
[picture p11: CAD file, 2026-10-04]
CEB_Press_v17.08/source/subassemblies/Cylinder_secondary_Subassembly.fcstd
110.5 x 1009.7 x 76.2 mm
pin_of_secondary_cylinder_01
secondary_cylinder_01

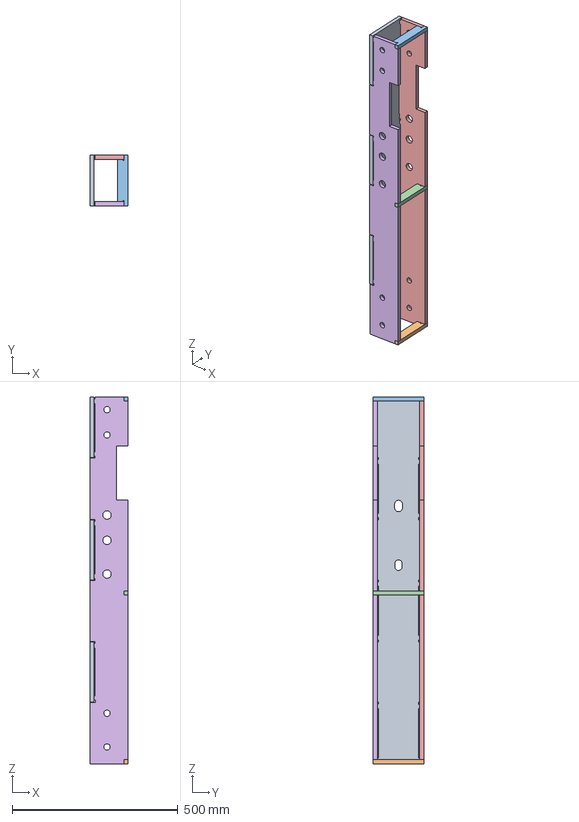
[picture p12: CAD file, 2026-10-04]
CEB_Press_v17.08/source/subassemblies/Frame/Main_Leg_Module.fcstd
115.1 x 152.4 x 1105.5 mm
Leg_Central_Plate_01
Leg_rib_01
Leg_rib_02
Leg_rib_03
Leg_Side_Plate_01
Leg_Side_Plate_02

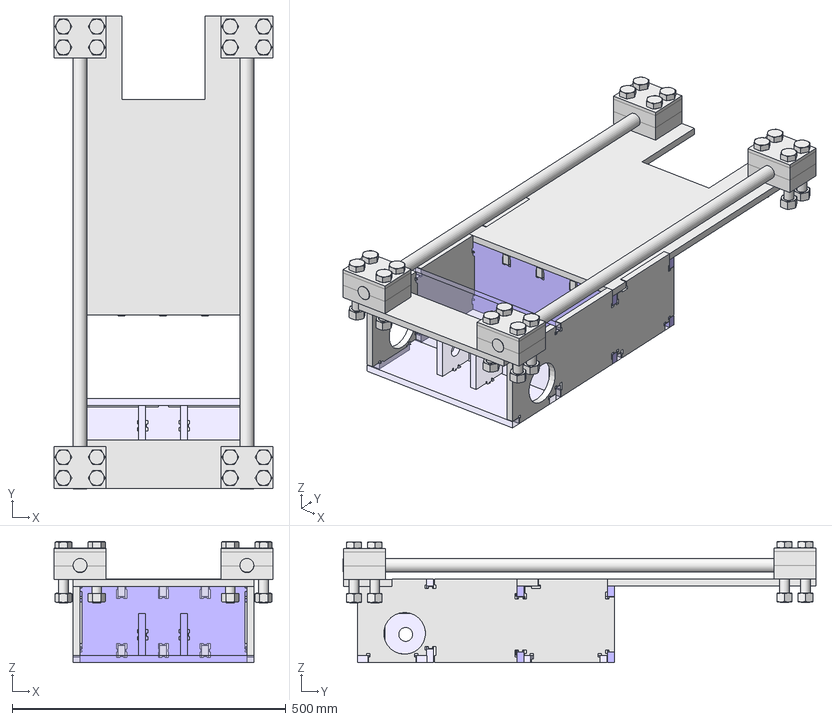
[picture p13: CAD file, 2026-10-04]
CEB_Press_v17.08/source/subassemblies/Drawer_SubAssembly.fcstd
400.1 x 863.6 x 221.7 mm
Drawer_Top_01
Drawer_side_01
Drawer_side_01001
Drawer_rod_attach_bar_01
Drawer_bottom_6259_01
Drawer_compression_plate_6267_01
Drawer_compression_plate_6267_01001
Drawer_compression_plate_6267_01002
Rod_holder_Module_01
Rod_holder_Module_01001
Rod_holder_Module_01002
Rod_holder_Module_01003
rod_01
rod_02

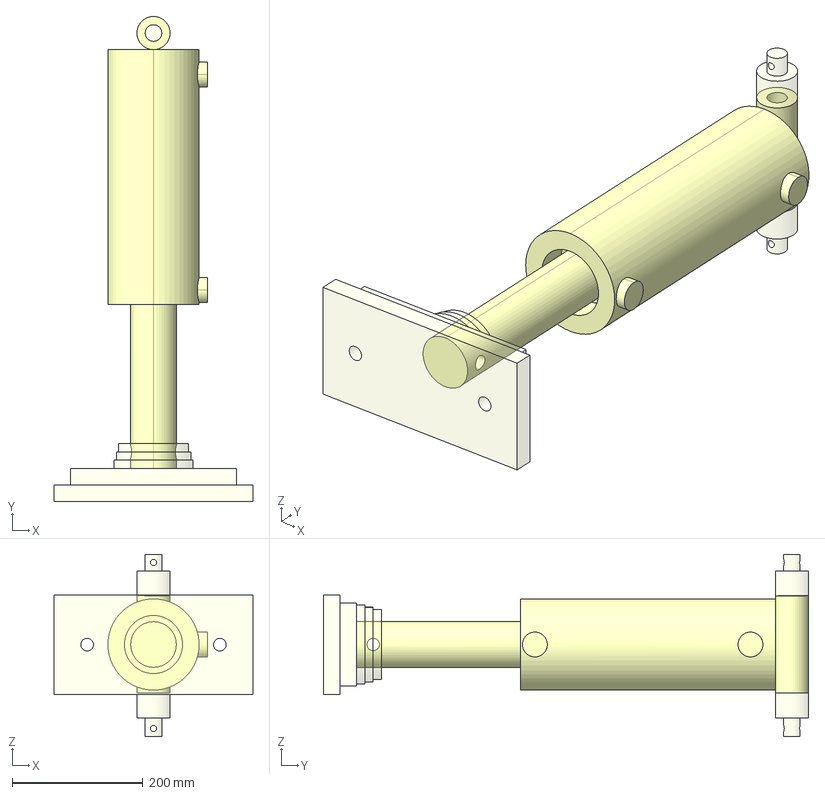
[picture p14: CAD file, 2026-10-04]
CEB_Press_v17.08/source/subassemblies/Cylinder_SubAssembly.fcstd
304.8 x 742.9 x 279.4 mm
main_cylinder_6337_01
bushing_01
bushing_02

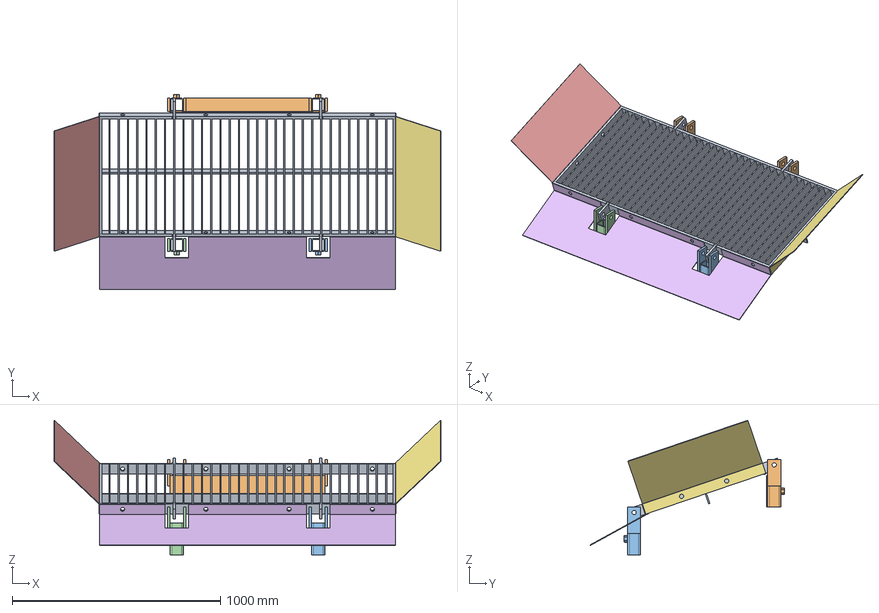
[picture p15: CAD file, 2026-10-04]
CEB_Press_v17.08/source/subassemblies/Crate_Subassembly.fcstd
1859.8 x 935.4 x 646.7 mm
crate_frame_module_01
crate_support_back_module_01
crate_support_square_tube_module_01
crate_support_square_tube_module_01001
_600_deflector_01
_602_deflector_01
_600_deflector_01001

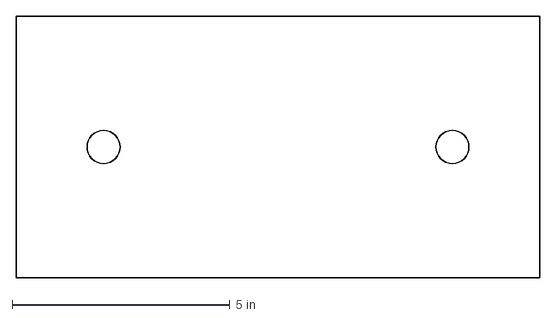
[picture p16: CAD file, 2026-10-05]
CEB_Press_v17.08/drawings/dxf/17_main_cylinder_02.dxf
12.0 x 6.00 in

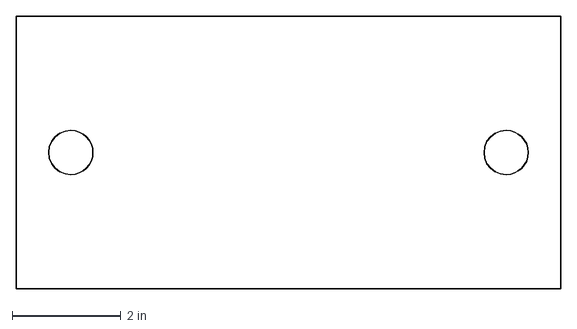
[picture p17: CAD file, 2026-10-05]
CEB_Press_v17.08/drawings/dxf/18_main_cylinder_03.dxf
10.0 x 5.00 in

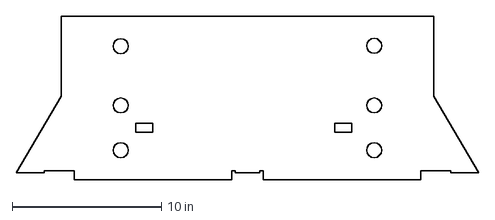
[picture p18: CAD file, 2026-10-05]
CEB_Press_v17.08/drawings/dxf/01_frame_01.dxf
31.1 x 11.0 in

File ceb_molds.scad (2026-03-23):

// CEB Dome Brick Molds — Frequency 14
// Standard frustum shapes: outer face larger, inner face smaller
// Outer/inner ratio: 0.96875 (R_inner/R_outer = 186.0/192.0)
// Units: inches

// PENTAGON skylight mold (outer edge 8.086", inner edge 7.833")
// MOLD: Pentagon skylight
// Outer edge: 9.506"
// Inner edge: 9.209"
// Depth: 7.00" (6.0" brick + 1.0" margin)
difference() {
  translate([0,0,3.500])
    cube([17.380,16.628,7.000], center=true);
  // Frustum cavity: outer face at top, inner face at bottom
  translate([0,0,1.0])
    hull() {
      linear_extrude(height=0.01) polygon(points=[[0.0000,7.8333],[-7.4499,2.4206],[-4.6043,-6.3372],[4.6043,-6.3372],[7.4499,2.4206]]);
      translate([0,0,6.0]) linear_extrude(height=0.01) polygon(points=[[0.0000,8.0859],[-7.6902,2.4987],[-4.7528,-6.5417],[4.7528,-6.5417],[7.6902,2.4987]]);
    }
}

translate([19, 0, 0]) {
// HEXAGON brick mold (outer edge 9.545", inner edge 9.247")
// MOLD: Hexagon brick
// Outer edge: 9.545"
// Inner edge: 9.247"
// Depth: 7.00" (6.0" brick + 1.0" margin)
difference() {
  translate([0,0,3.500])
    cube([21.090,18.532,7.000], center=true);
  // Frustum cavity: outer face at top, inner face at bottom
  translate([0,0,1.0])
    hull() {
      linear_extrude(height=0.01) polygon(points=[[9.2466,0.0000],[4.6233,8.0078],[-4.6233,8.0078],[-9.2466,0.0000],[-4.6233,-8.0078],[4.6233,-8.0078]]);
      translate([0,0,6.0]) linear_extrude(height=0.01) polygon(points=[[9.5449,0.0000],[4.7724,8.2661],[-4.7724,8.2661],[-9.5449,0.0000],[-4.7724,-8.2661],[4.7724,-8.2661]]);
    }
}
}

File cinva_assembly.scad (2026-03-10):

/*
 * CINVA-Ram Block Press — Assembly Model
 *
 * Shows all parts in their assembled positions.
 * Based on engineering drawings (cinva0-7) and
 * reference photos (Blockpress*.jpg).
 *
 * Coordinate system:
 *   X = left / right
 *   Y = front (toward operator) / back (toward baseboard)
 *   Z = up / down (vertical)
 *
 * Units: inches.
 */

use <cinva_ram.scad>;

$fn = 48;

T = 0.250;

// ============================================================
// Key reference positions
// ============================================================

// Baseboard stands vertical at the back (Y=0 plane)
// 15" wide in X, 12" tall in Z
baseboard_w = 15.000;
baseboard_h = 12.000;

// Mold box is centered on baseboard in X
// Side walls face X (thin in X), extend in Y away from baseboard
// End walls face Y (thin in Y), span between side walls
mold_inner_w = 6.000;   // between side walls (X), = short end wall width
mold_inner_d = 6.750;   // between end walls (Y), = side wall width - 2*T
side_wall_len = 7.250;  // side wall dimension in Y
side_wall_h = 6.000;    // side wall height

// Mold box bottom Z — sits above the baseboard slot
mold_z = 6.500;

// Mold box centered on baseboard
mold_x_left = (baseboard_w - mold_inner_w) / 2 - T;  // left side wall outer face

// Baseboard pivot hole (for handle)
pivot_x = 5.000;
pivot_z = 9.500;

// Piston position (adjustable — 0 = flush with mold bottom)
piston_rise = 0.0;  // set to ~4 for "pressed" position

// Handle angle (0 = horizontal, positive = raised)
handle_angle = 45;  // degrees from horizontal

// Cover angle (0 = closed, 90 = fully open)
cover_angle = 70;


// ============================================================
// Colors for clarity
// ============================================================

clr_frame     = [0.45, 0.42, 0.40];  // baseboard, dark steel
clr_mold      = [0.55, 0.52, 0.50];  // mold box walls
clr_piston    = [0.60, 0.58, 0.55];  // piston
clr_cover     = [0.50, 0.48, 0.45];  // cover
clr_handle    = [0.40, 0.38, 0.35];  // handle
clr_toggle    = [0.65, 0.55, 0.45];  // toggle links
clr_bearing   = [0.50, 0.45, 0.40];  // bearing plates
clr_latch     = [0.55, 0.50, 0.45];  // latch
clr_pin       = [0.70, 0.70, 0.70];  // pivot pins


// ============================================================
// 1" diameter pivot pins (shop-made from round bar)
// ============================================================

module pin(length) {
    color(clr_pin)
        cylinder(d=0.95, h=length, center=true);
}


// ============================================================
// BASEBOARD (Part D) — vertical frame plate
// ============================================================

module assy_baseboard() {
    color(clr_frame)
    // Stand the baseboard vertical in XZ plane at Y=0
    translate([0, T, 0])
        rotate([90, 0, 0])
            D_Side();
}


// ============================================================
// MOLD BOX (Part C) — four walls welded into open-ended box
// ============================================================

module assy_mold_box() {
    // Left side wall — stands in YZ plane
    color(clr_mold)
    translate([mold_x_left, T, mold_z])
        rotate([0, 0, 0])
            cube([T, side_wall_len, side_wall_h]);

    // Right side wall
    color(clr_mold)
    translate([mold_x_left + T + mold_inner_w, T, mold_z])
        cube([T, side_wall_len, side_wall_h]);

    // Short end wall (near baseboard)
    // Fits between side walls
    color(clr_mold)
    translate([mold_x_left + T, T, mold_z])
        cube([mold_inner_w, T, 11.500]);

    // Tall end wall (far from baseboard)
    // 6.500" wide — extends 0.250" past each side wall
    color(clr_mold)
    translate([mold_x_left + T - 0.250, T + side_wall_len - T, mold_z])
        cube([6.500, T, 12.000]);
}


// ============================================================
// PISTON (Part K) — slides vertically inside mold box
//
// The piston is a rectangular body topped with the 6x6 cap.
// The body extends below the mold box through the guide plates.
// A 1" hole through the body connects to the toggle mechanism.
// ============================================================

module assy_piston() {
    cap_size = 5.750;  // slightly smaller than cavity for clearance
    body_h = 4.000;    // piston body below cap
    body_w = 1.750;    // body width (visible in Blockpress003.jpg)
    body_d = 5.500;    // body depth

    piston_z = mold_z + piston_rise;

    color(clr_piston) {
        // Cap — top pressing face
        translate([mold_x_left + T + (mold_inner_w - cap_size)/2,
                   T + T + (mold_inner_d - cap_size)/2,
                   piston_z])
            cube([cap_size, cap_size, T]);

        // Body — extends below cap
        translate([mold_x_left + T + (mold_inner_w - body_w)/2,
                   T + T + (mold_inner_d - body_d)/2,
                   piston_z - body_h])
            difference() {
                cube([body_w, body_d, body_h]);
                // 1" pivot hole through body (for toggle pin)
                translate([-0.1, body_d/2, body_h * 0.3])
                    rotate([0, 90, 0])
                        cylinder(d=1.000, h=body_w+0.2);
            }
    }
}


// ============================================================
// GUIDE PLATES (Parts I & J) — welded to mold box bottom
// ============================================================

module assy_guide_plates() {
    color(clr_bearing) {
        // Left guide plate — on left side wall, below mold box
        translate([mold_x_left - 0.5, T + side_wall_len/2 - 1.5, mold_z - 2.5])
            rotate([0, 0, 0])
                cube([T + 0.5, 3.000, 2.500]);

        // Right guide plate
        translate([mold_x_left + T + mold_inner_w, T + side_wall_len/2 - 1.5, mold_z - 2.5])
            cube([T + 0.5, 3.000, 2.500]);
    }
}


// ============================================================
// UPPER SADDLE / BEARING PLATES (Part B)
// Welded to piston body, provide pivot for toggle links
// ============================================================

module assy_bearing_plates() {
    piston_z = mold_z + piston_rise;
    body_h = 4.000;
    plate_z = piston_z - body_h * 0.7;

    color(clr_bearing) {
        // Left bearing plate on piston body
        translate([mold_x_left + T + mold_inner_w/2 - 1.5 - T,
                   T + side_wall_len/2 - 1.000,
                   plate_z - 1.000])
            rotate([90, 0, 0])
                translate([0, 0, 0])
                    cube([3.000, 2.000, T]);

        // Right bearing plate
        translate([mold_x_left + T + mold_inner_w/2 + 1.5,
                   T + side_wall_len/2 - 1.000,
                   plate_z - 1.000])
            rotate([90, 0, 0])
                cube([3.000, 2.000, T]);
    }
}


// ============================================================
// HANDLE (Part N) — pivots at baseboard, operator pulls down
// ============================================================

module assy_handle() {
    bar_len = 19.625;
    bar_w = 2.000;
    cross_upper = 11.000;
    cross_lower = 8.000;

    // Handle spacing (distance between the two bars)
    bar_spacing = 6.000;

    color(clr_handle)
    // Pivot at baseboard hole
    translate([pivot_x, T/2, pivot_z])
        rotate([0, -handle_angle, 0]) {
            // Pivot is 1" from end of bar, so offset
            translate([-1.000, -bar_spacing/2 - bar_w/2, -bar_w/2]) {
                // Left handle bar
                cube([bar_len, bar_w, T]);

                // Right handle bar
                translate([0, bar_spacing + bar_w - T, 0])
                    cube([bar_len, bar_w, T]);

                // Upper cross bar (near pivot end)
                translate([0.5, bar_w, 0])
                    cube([T, bar_spacing - T, bar_w]);

                // Lower cross bar (toward grip end)
                translate([bar_len * 0.6, bar_w + (bar_spacing - cross_lower + bar_w)/2, 0])
                    cube([T, cross_lower - bar_w, bar_w]);
            }
        }
}


// ============================================================
// TOGGLE LINKS — connect handle to piston
// Two pairs: long links (upper) and short links (lower)
// ============================================================

module assy_toggle_links() {
    // Approximate toggle positions
    // Upper pivot: on the handle, near the cross bar
    // Lower pivot: on the piston bearing plates

    piston_z = mold_z + piston_rise;
    toggle_upper_z = pivot_z - 2.0;  // below handle pivot
    toggle_lower_z = piston_z - 3.5; // at piston bearing plates

    link_y_offset = T + side_wall_len/2;
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

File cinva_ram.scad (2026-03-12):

/*
 * CINVA-Ram Block Press — OpenSCAD Solid Model
 *
 * All dimensions from engineering drawings (cinva1-7.jpg).
 * Material: 1/4" (0.250") steel plate throughout.
 * Units: inches.
 *
 * Usage: Open in OpenSCAD. Each part is a named module.
 * The layout at the bottom spreads all 22 parts for viewing.
 */

$fn = 64;

T = 0.250;  // plate thickness (1/4")


// ==========================================================
// Helper modules
// ==========================================================

module plate(w, h, t=T) {
    cube([w, h, t]);
}

module plate_with_hole(w, h, hole_d, hole_x, hole_y, t=T) {
    difference() {
        cube([w, h, t]);
        translate([hole_x, hole_y, -0.01])
            cylinder(d=hole_d, h=t+0.02);
    }
}

// Rectangle with radiused bottom corners, square top corners
module rounded_bottom_rect(w, h, r, t=T) {
    linear_extrude(height=t) {
        union() {
            // upper portion (above radius)
            translate([0, r])
                square([w, h - r]);
            // bottom-left radius
            translate([r, r])
                circle(r=r);
            // bottom center fill
            translate([r, 0])
                square([w - 2*r, r]);
            // bottom-right radius
            translate([w - r, r])
                circle(r=r);
        }
    }
}

// Rectangle with all four corners radiused
module rounded_rect(w, h, r, t=T) {
    linear_extrude(height=t)
        offset(r=r)
            offset(delta=-r)
                square([w, h]);
}



// ==========================================================
// SHEET 2 — Wing and Tail plates (from cinva2.jpg)
//
// Wing: 2.000 x 5.625 (3.625 + 2), 1" hole, R0.375" bottom corners
// Tail: 2.000 x 3.625, 1" hole at 1.250" from bottom, R0.375" bottom corners
// Welded in pairs (Wing+Tail) to make 0.5" thick assemblies
// ==========================================================

module toggle_link(width, height, hole_y) {
    difference() {
        rounded_bottom_rect(width, height, 0.375);
        translate([width / 2, hole_y, -0.01])
            cylinder(d=1.000, h=T+0.02);
    }
}

module Wing() {
    difference() {
        toggle_link(2.000, 5.625, 1.250);
        // Second hole aligns with Pivot Y-through hole
        translate([1.000, 4.625, -0.01])
            cylinder(d=1.000, h=T+0.02);
    }
}

module Tail() {
    toggle_link(2.000, 3.625, 1.250);
}


// ==========================================================
// SHEET 3 — Clamp
// Clamp — latch bracket from cinva3.jpg
// Two horizontal lines (tab 0.309, bar 2.929) with angled notch between
// Notch: 0.354 and 0.518 walls (parallel, 13.3° from vert), 0.625 bottom
// Left face: 1.035 hypotenuse (vert 1.000, horiz 0.267)
module Clamp() {
    difference() {
        linear_extrude(height=T)
            polygon(points=concat(
                // bottom-left R0.250 round (center 0.250, 0.250)
                [for (a = [180:10:270]) [0.250 + 0.250*cos(a), 0.250 + 0.250*sin(a)]],
                [[2.929, 0],         // bar bottom-right (horiz 2.929)
                [3.048, 0.504],     // notch right (0.518 parallel wall)
                [3.652, 0.345],     // notch left (0.625 bottom)
                [3.571, 0],         // tab bottom-left (0.354 parallel wall)
                [3.880, 0],         // tab bottom-right (horiz 0.309)
                [4.147, 1.000]],    // top of angled face
                // top-left R0.250 round (center 0.250, 0.750)
                [for (a = [90:10:180]) [0.250 + 0.250*cos(a), 0.750 + 0.250*sin(a)]]
            ));
        // 0.437" dia hole — 0.397" from left end, centered in 1" height
        translate([0.397, 0.500, -0.01])
            cylinder(d=0.437, h=T+0.02);
    }
}

module Spacer() {
    plate(1.000, 2.750);
}





// ==========================================================
// SHEET 7 — Baseboard and Piston
//
// 1x baseboard:  15.000 x 12.000
//    1.000" dia pivot hole, 2x 0.500" bolt holes
//    8.000 x 2.000 piston slot (5" from bottom, 5" from right)
// 1x piston cap:  6.000 x 6.000
// ==========================================================

module Side() {
    w = 15.000;
    h = 12.000;

    difference() {
        cube([w, h, T]);

        // 1.000" dia toggle pivot hole — centered on width, 1" from top edge
        translate([w/2, 11.000, -0.01])
            cylinder(d=1.000, h=T+0.02);

        // 0.500" dia mounting bolt holes — below slot, for bolting to feet
        translate([1.000, 3.000, -0.01])
            cylinder(d=0.500, h=T+0.02);
        translate([1.000, 9.000, -0.01])
            cylinder(d=0.500, h=T+0.02);

        // 8.000 x 1.000 rectangular piston slot — bottom barely touches Load bar
        translate([3.150, 5.500, -0.01])
            cube([8.000, 1.000, T+0.02]);
    }
}

// --- Shelf: flat plate the brick sits on, spans between slotted sides ---
module Shelf() {
    plate(6.000, 12.000);
}

// --- Shelf bracket: 11x2x0.25, welded under shelf ---
module Bracket() {
    plate(11.000, 2.000);
}

// --- Piston plate: 6x6x0.25, welded in pairs (0.5" thick) ---
// 1.000" dia hole at 0.500" from bottom, centered on width
module Piston() {
    plate_with_hole(6.000, 6.000, 1.000, 3.000, 0.500);
}

// --- End plate: 7.5x6.5x0.25, welded to outside of shelf ---
module EndPlate() {
    plate(7.500, 6.500);
}


// ==========================================================
// Pivot — solid block connecting handle to Load pin
//
// 2x2x6 block with:
//   1x4" rectangular slot (for handle bars to pass through)
//   1" dia hole (for Load pivot pin)
// Based on Blockpress003.jpg
// ==========================================================

module Pivot() {
    // 2x2 in X/Y, 6" tall in Z
    // Sunk slot faces up, 1" hole through Y for Spacer
    // 2x2x2 block at top toward front with 1" hole
    difference() {
        union() {
            cube([2, 2, 6]);
            // Front block at top — 1.000(X) x 2(Y) x 1.000(Z)
            translate([-1.000, 0, 6 - 1.000])
                cube([1.000, 2, 1.000]);
        }

        // 1" dia x 4" deep sunk hole from top — centered in X/Y
        translate([1, 1, 2])
            cylinder(d=1.000, h=4.01);

        // 1" dia hole through in Y — 1" from bottom, centered in X
        // Aligns with Spacer / ramp scoops
        translate([1, -0.01, 1])
            rotate([-90, 0, 0])
                cylinder(d=1.000, h=2.02);

        // 0.437" dia hole through front block in Y — 0.397" from front edge, centered vertically
        translate([-1.000 + 0.397, -0.01, 6 - 0.500])
            rotate([-90, 0, 0])
                cylinder(d=0.437, h=2.02);

    }
}


// ==========================================================
// Top plate — 12.5x6.5, sits on top of the side plates
// ==========================================================

module Top() {
    plate(12.500, 6.500);
}


// ==========================================================
// Ramps — V-shaped plates on top of the top plate
//
// Based on cinva5.jpg cover geometry:
//   12.000" span, left leg 6.038", right leg 4.810"
//   V drop ~0.72"
// Scaled to 12.500" span (matching top plate width)
// Depth 6.500" (matching top plate)
// ==========================================================

module Ramp(depth=6.500) {
    // Solid ramp from cinva5.jpg
    // Start simple: 12" bottom, 1" right edge, 0.25" left edge
    // 6 sides + R0.625" arc scoop at peak:
    //   12" bottom, 1" left up, 4.810" slope up-right,
    //   1" horizontal, R0.625" scoop, 6.038" slope down-right, 0.25" right down
    // Peak height ~3.0"
    // Gap = 1" horizontal + 1.25" arc = 2.25"

    peak_y = 3.0;
    left_peak_x = 4.374;     // 4.810" slope from (0,1)
    right_peak_x = 6.624;    // 6.038" slope to (12,0.25)

    linear_extrude(height=depth)
        difference() {
            polygon(points=[
                [0, 0],
                [12, 0],
                [12, 1],
                [12 - left_peak_x, peak_y],
                [12 - right_peak_x, peak_y],
                [0, 0.25],
            ]);
            // R0.625" scoop at peak center
            translate([12 - right_peak_x + 0.625, peak_y])
                circle(r=0.625);
        }
}


// ==========================================================
// Foot Brackets — L-shaped mounting feet
//
// 2x foot bracket: weld vertical leg to baseboard bottom,
//    horizontal leg provides bolt-down surface
//    Vertical leg: 4.000 x 3.000
//    Horizontal leg: 4.000 x 3.000
//    0.500" dia bolt hole centered in horizontal leg
// ==========================================================

module Base_Bracket() {
    len  = 36.000;  // 3 feet long
    leg  = 2.000;   // 2" x 2" L profile
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

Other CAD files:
CEB_Press_v17.08/source/subassemblies/File CEB_17.08_CAD_Assembly.fcstd
CEB_Press_v17.08/osrl/drawings/dxf/06_hinge.dxf
CEB_Press_v17.08/press6/drawings/dxf/10_01_131_00_0_lf5.dxf
CEB_Press_v17.08/shaker/drawings/dxf/08_hhead.dxf
ceb_dome.scad
CEB_Press_v17.08/drawings/dxf/02_frame_02.dxf
CEB_Press_v17.08/drawings/dxf/03_frame_03.dxf
CEB_Press_v17.08/drawings/dxf/04_frame_04.dxf
CEB_Press_v17.08/drawings/dxf/05_frame_05.dxf
CEB_Press_v17.08/drawings/dxf/06_frame_06.dxf
CEB_Press_v17.08/drawings/dxf/07_frame_07.dxf
CEB_Press_v17.08/drawings/dxf/08_frame_08.dxf
CEB_Press_v17.08/drawings/dxf/09_frame_09.dxf
CEB_Press_v17.08/drawings/dxf/10_frame_10.dxf
CEB_Press_v17.08/drawings/dxf/11_frame_11.dxf
CEB_Press_v17.08/drawings/dxf/12_hopper_seat_01.dxf
CEB_Press_v17.08/drawings/dxf/13_hopper_seat_02.dxf
CEB_Press_v17.08/drawings/dxf/14_hopper_seat_03.dxf
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

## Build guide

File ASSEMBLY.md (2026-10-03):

# Simple CINVA-Ram Press, 14 x 7 x 4 — Welding & Assembly Guide

Fabrication sequence for the press in `drawings/simple-14x7x4/` (drawing set `SCR-14x7x4-00` to `-23`).
Part numbers below are the item numbers on the parts list (sheet 1). All dimensions in inches.

This press is a scale-up of the permies.com replica (thread 33406). His part drawings are
`cinva1-7.jpg`; the SketchUp model and his video show how the parts go together. Each of his
parts is scaled from his 11.5 x 6 x 3-5/8 brick to our 14 x 7 x 4:
- lengths along the mold x 1.217;
- widths across it x 1.167;
- heights x 1.102 (his 6-1/8 loose fill becomes 6-3/4).

The heavy-duty version, with a claw latch and an eject roller on posts, is in `ASSEMBLY_full.md`.

**How it works (read this first).**
- **Mold, piston and yoke.** The piston slides in the mold box. Main pin **P** runs through its four
  webs, out through vertical slots in both side plates, and into the two **yoke arms** outside the box.
  At the top the arms are tied by two **cross bars** into a box. They carry the **head** on two stub
  pins **Q**.
- **The head (his "L-cam").** It is shaped like an L: pin Q at the corner, the **cam pin** at the foot,
  2.132 from Q, and the handle along the other leg.
- **The ramps.** The two **V ramps** on the lid each have a half-round **scoop** at the peak, right over
  the middle of the mold.
- **Pressing.** Stand the yoke up, and the cam pin rides up the long leg of the ramps and drops into the
  scoops. Pulling the handle over then works like straightening a knee: the head pivots on the cam pin
  and swings Q up and over it. The yoke lifts the piston 2.75, squeezing the soil against the lid.
- **The lock.** At 3 deg past straight, the cheeks land on the two **handle rests** and the handle stays
  down on its own.
- **Where the force goes.** Through the brick, piston, pin P, yoke, pins Q, cam pin, ramps and lid. It
  does **not** go through the mold box welds.
- **Latch.** His **latch hooks** (item 20) hang from the head and drop over the pull-end cross bar. That
  holds head and yoke together while you tilt them.
- **Ejecting.** With the lid swung over, the yoke leans on the two **fixed pins** on the side plates.
  Pushing the handle down levers the piston up and the brick out.

See sheet 3 for the four positions and sheet 4 for the operating steps and loads.

## What changed from his drawings, and why

| Item | Part | His drawing | This press | Reason |
|---|---|---|---|---|
| 1 | Side plate slot | 2.000 wide for a 1 in pin | pin + 1/16 (1.813) | **His error**: the supplier later changed it to 1 in; a 2 in slot lets the pin wander |
| 1 | Side plate slot top | ends 1 in into the chamber | ends below the loose soil | soil would push out through the slot at fill |
| 4 | Fixed pins | 7.71 up (7 x 1.102) | 7.48 up | set so the eject stroke ends at 80 deg with the wider 3 in arms |
| 1 | Side plate | 1/4 plate | 5/8 plate | soil pressure on a 14 in wall (1/2 left a 7% stress margin; trade study in `sysml_trade.py`) |
| 2 | End plate | 1/4, 6 x 6 | 1/2, 7 x 7.5 | spans 7 in; reaches the piston at fill |
| 6 | Lid plate | 1/4, covers the side plates | 5/8; narrow except at the pull end | would dish; the head swings down past its edges while standing up |
| 7 | V ramp | 1/4 | 3/4 AR400 | the cam pin carries the whole press force in the scoop |
| 10, 11 | Piston cap, webs | 1/4 | 1/2 cap, 3/8 webs | cap would dish |
| 12 | Yoke arm | 2 x 1/4 bar | 3 x 1/2 plate, 2.3 in longer | pin loads; room for the cross-bar box over the head |
| 14, 16, 17 | Pins P, Q, cam | 1 in mild steel | 1-3/4, 1-1/4, 1-3/8 4140 prehard | 1 in mild-steel pins bend at 20,000 lbf; 1-1/4 cam pin left a 6% margin |
| 15 | Head | his link plates and 3 x 2 plates | one L-shaped cheek per side | same job, fewer pieces |
| 20 | Latch hook | notch on the side | notch at the tip | the hook drops straight onto the cross bar |

Two more changes:
- **The lid swings on his 11 in bars.** They pivot on pins near the bottom of the side plates at the
  pull end, so the lid swings over onto the stand.
- **The press bolts to a 12 in stand** that reaches 12 in past the pull end. This keeps the eject
  stroke at a workable height (the grip ends 23 in above the ground), and the open lid lies on it.
  The stand is detailed since rev F (items 39 to 42, Step 10).

## General welding rules

- Process: SMAW with E7018 or GMAW with ER70S-6. Fillet welds 1/4 unless noted.
- **AR400 ramps (item 7):** low-hydrogen only, preheat the joint to 300 F, cool slowly under a blanket.
- **No weld, spatter or grinding marks inside the mold or on the lid underside.** Weld outside only.
- **4140 pins (items 14, 16, 17):**
  - Weld only the Q stubs into the cheeks and the cam pin ends to the cheeks.
  - Keep those welds small and cool them slowly.
  - Never weld pin P.
- Line-bore the piston web holes for pin P after welding.
- Tack, check, then run final welds in short alternating passes.

## Purchased and turned items

| Item | Part | Stock / spec | Qty | Notes |
|---|---|---|---|---|
| 4 | Fixed pin | 1.250 round 1018, 1.563 long | 2 | Welded in the side plates |
| 5 | Lid pivot pin | 1.000 round 1018, 1.531 long | 2 | Washer and 1/8 cotter outside the strap |
| 14 | Main pin P | 1.750 round 4140 prehard, 10.625 long | 1 | Two 9/32 cross holes, 1/4 hitch pins |
| 16 | Pin Q (stub) | 1.250 round 4140 prehard, 1.688 long | 2 | One 9/32 cross hole each |
| 17 | Cam pin | 1.375 round 4140 prehard, 8.250 long | 1 | |
| 19 | Handle | 2 sch 160 pipe, 82.0 long | 1 | Grip end 90 from Q (rev G: was 2 sch 80; rev E: 1-1/2 sch 80, 66.0 / 74) |
| 22 | Latch pivot | 0.500 round 1018, 8.250 long | 1 | Cotter each end |
| 23 | Lid handle | 0.500 round 1018, bent into a U (horseshoe), 4 between legs | 1 | About 11 in of bar |
| — | Hardware | 1/2 bolts (4) for the foot clips, 1/4 hitch pins (4), 1/8 cotters (4), washers | | |
| — | Grease | lithium grease for pins P and Q, the scoops, the cam pin and the fixed pins | | |

Cut all plates from the DXF files in `drawings/simple-14x7x4/dxf/` (1:1, inches).
**The V ramp top edge and scoop must come from the DXF**: the scoop position sets the stroke.

## Step 1 — Mold box (items 1, 2, 3, 4, 5)

1. Cut both side plates from the DXF. Each has:
   - the corrected slot, centred on the length;
   - the fixed-pin hole, near the top at one end;
   - the lid-pivot hole, at the other end;
   - two 9/16 bolt holes along the bottom.
   The two plates are identical; one is flipped to face the other.
2. Stand the side plates on a flat table 7.000 apart (inside faces). Set the end plates between them,
   flush with the top edges and the plate ends.
3. Square the box: inside 14.000 x 7.000 at the top, diagonals equal within 1/32. Clamp stiff bars
   across top and bottom and weld the end plates outside only.
4. Slide a straight 1-3/4 bar through both slots: it must pass freely over the full length.
5. Weld the fixed pins (item 4) through their holes, inner end flush inside, and the lid pivot pins
   (item 5) the same way. Keep both square to the plates.
6. Bolt the four foot clips (item 3) through the bottom holes. The two at the pull end sit 3 in in from
   the plate end so the lid straps swing past them. Bolt or lag the clips to the stand.

## Step 2 — Piston (items 10, 11)

1. Weld the four webs under the cap in two pairs. The outer webs sit flush with the cap's long edges;
   the inner ones sit 1/2 inboard of them. All four are centred on the cap length.
2. Line-bore the 1.781 holes for pin P through all four webs after welding, 1.102 above the web bottoms.
3. The piston must slide the full depth of the mold with about 1/16 all round.

## Step 3 — Lid (items 6, 7, 8, 9)

1. Cut the lid plate from the DXF. It is 6.969 wide (inside the side plates) except the last 3 in at the
   pull end, which is full width and sits on the side plates.
2. Weld the V ramps along both long edges of the lid top, outer faces 3.563 from the centreline.
   - Put the long leg (lower end 0.276) at the fixed-pin end.
   - The scoops sit right over the middle of the mold.
   - Use low-hydrogen rod and preheat.
3. Weld the lid straps (item 8) to the edges of the wide part, reaching down to the lid pivot pins.
4. Weld the two handle rests (item 9) on the wide part along each edge, under where the head cheeks
   land. Fit them in Step 7.
5. Bend the lid handle (item 23) from 1/2 round into a U, 4 between leg centres, 3.25 overall. Weld the
   leg ends to the lid's fixed-pin end face, centred and level with the lid, so the U sticks straight
   out. Lift the lid by it to swing the lid over onto the stand, and to swing it back.

## Step 4 — Yoke (items 12, 13)

1. Cut both arms from the DXF and drill P and Q with the arms clamped together.
2. Weld the two cross bars (item 13) on edge between the arm tops to make a box. The pull-end bar's outer
   face is 0.875 from the arm centreline; the other is its mirror.
   - The head rests on the pull-end bar's lower edge.
   - The latch hooks drop over its top edge.

## Step 5 — Head (items 15 to 22)

1. Cut both cheeks from the DXF. Clamp them together and drill:
   - Q (1.250);
   - the cam pin (1.391), **2.132 below Q, hold +/-0.010**;
   - the latch pivot (0.531).
2. Weld a Q stub (item 16) into each cheek, inner end flush inside, sticking out.
3. Weld the two bridges (item 18) between the cheeks at the far end of the handle leg, 9.25 and 11.5 from
   Q (rev E: moved out so the open latch bar clears them); slide the handle (item 19) through both and weld all round.
4. Push the cam pin (item 17) through both cheeks, flush outside; weld the ends.
5. Weld the latch bar (item 21) across the two latch hooks (item 20). Hang them between the cheeks on the
   latch pivot (item 22), with a cotter at each end.

## Step 6 — Final assembly

1. Lower the piston into the mold from the top until its holes line up with the slots.
2. Hang the yoke arms outside the side plates and push pin P through: arm, slot, four webs, slot, arm.
   Hitch pins outside the arms.
3. Fit the head between the arm tops with the Q stubs in the arms' Q holes; washers and hitch pins
   outside. Grease.
4. Put the lid straps on the lid pivot pins; washers and cotters.

## Step 7 — Adjust and test (empty)

1. **Fill position:** lid swung over onto the stand by its handle, latch shut, yoke leaning on the fixed pins at about
   33 deg.
2. Swing the lid on and lift the handle and yoke upright. The cam pin must ride up the long leg of both
   ramps and drop into both scoops. The piston lifts about 3/4 on the way and settles back.
3. Lift the latch bar. Pull the handle over: the piston top should rise from 6.750 to 4.000 below the mold
   top. The cheeks land on the handle rests with the handle 3 deg below horizontal.
   - Grind or shim the rests so the stop is exactly there.
   - The handle must stay down by itself.
4. Raise the handle back past upright, drop the latch, tilt back onto the fixed pins, and swing the lid
   over. Push the handle down: the piston top must come up 1/8 above the mold top with the yoke at
   about 80 deg.
5. Grease the scoops, cam pin, pins P and Q and the fixed pins.

## Step 8 — Load test before production

Press a few light fills, then work up to a full 6.750 loose fill.
- **Handle force:** the peak comes about 70% of the way through the pull, with the grip about 67 in
  above the ground (head height), not at the end: the over-centre geometry takes the force away in the last
  few degrees before the lock. Peak 98 lbf at 150 psi, 131 at 200, 190 at 290 psi on the 90 in handle
  (rev E), with the grip about 76 in up at the peak.
- **Ergonomic limit:** 120 lbf for pulling down above head height (CCOHS Table 2, from Kodak's *Ergonomic
  Design for People at Work*). One operator stays under it up to about 180 psi. The pressure is set by
  the soil, not the operator: measure it in the load test (peak pull / 0.65 = psi on this handle). For
  repetitive work CCOHS recommends considerably lower forces.
- **Handle pipe (rev G):** 2 sch 160, 50 lb: +44% margin at the bridge at the 306 psi design load. The bending
  moment at the head is the same for any handle length (force x length); 1-1/2 sch 80 yields at about 290 psi,
  2 sch 80 had +7%. The heavier pipe takes about 25 lbf at the grip to lift back past upright.
- **After 20 bricks:** check that pins P, Q and the cam pin are straight, the scoops are not dented,
  the side plates have not bulged, and no weld has cracked.
- **If the head will not reach the rests**, the fill is too heavy. Take soil out; don't force it.

## Step 9 — Feeder (items 24 to 38, rev C)

A funnel on a sliding feed box, parked on the **+Y side** (the side you shovel from). It slides across the
mold top at fill only.

**Why it is laid out this way.**
- Everything that moves above the mold stays within 5.31 of the centreline over the whole cycle (the Q stubs).
  The lid swings over the pull end and the yoke leans over the fixed-pin end, so the only free side is ±Y.
- The yoke arms, Q stubs and lid straps sweep the strip from the side plate out to y 5.875, so nothing fixed
  can bridge it. The box therefore has a **knife-gate floor**: shut while it crosses that gap, pulled open over
  the mold, pushed shut again. Pushing it shut shears the charge off level with the mold top, so every
  brick gets the same loose volume.
- At fill the head cheek tips hang 0.9 to 2.7 above the mold top over the first 1.4 at the fixed-pin end.
  The box's pin end is a 3/4 lip and a 45 deg chute that pass under them (0.36 clearance); the chute is
  steeper than the soil's angle of repose, so that end of the mold still fills.
- The rail bracket and stop post bolt to the side plates at x 9.25 to 11.25: the yoke arms reach no further
  than x 8.62 and the lid straps start at x 11.83.

**Fabrication.**
1. Cut the lid end wall (25), strike wall (26) and stop lug (31) from the DXFs. Bend the pin end (24) and the
   funnel wall (27) to their sheets: 10 ga, lip / chute / upright, and upright / 30 deg flare.
2. Tack the box square on a flat table: strike wall across both end walls, funnel wall between them. The
   strike wall's bottom edge is the strike-off: keep it straight and flush. The end walls and funnel wall stand
   7/32 up off the table (the gate runs under them); shim them while tacking. Weld outside only.
3. Weld the stop lug to the strike wall outside, 1/4 up from its bottom edge, at x 9.5 to 11.0.
4. Gate (28): bevel the leading edge on top, 30 deg. Weld the 3/16 square stop strip across it and the gate
   handle (29) on its tail. Weld the box handle (30) to the flared face, 11 up.
5. Frame: weld the two rails (32) on the near tie (33) and against the far tie's upright leg (34), upright
   legs outside and 1/16 clear of the box walls. Weld the legs (35) and leg tie (36).

**Fitting.**
1. Drill both side plates for the two new 9/16 holes (rev C): 10.25 and 11.25 from the plate's fixed-pin end
   (9.75 and 10.75 from the inside of the mold), 2.25 below the top edge. Both plates stay identical.
2. Bolt the rail bracket (37) to the +Y side plate and the stop post (38) to the -Y side plate, 1/2 bolts.
3. Set the frame on the bracket with the rail tops level with the mold top (shim the legs), bolt the near tie
   to the bracket, and lag or stake the legs.
4. With the press at fill, slide the empty box over: the lug must land on the post with the box square over
   the mold, and the tails still between the rails. Pull the gate open: it stops 3/16 short of the far wall.
5. Cycle the press through stand-up, pressing and eject with the box parked: nothing may touch it.

**Use** (fill step): shovel into the funnel (it holds about 2.3 charges). Push the box over by the gate handle
until the lug stops on the post. Hold the box handle, pull the gate open, tap the box. Push the gate shut and
pull the box back to park by its handle. Only then swing the lid on and stand the yoke up.

## Step 10 — Stand (items 39 to 42, rev F)

A welded steel frame, 12 high, reaching 12 past the pull end so the open lid lies on it.

**Why it is laid out this way.**
- The rails (3 x 2 x 3/16 rect tube, 3 side up) carry both the side plates' bottom edges and the foot
  clips, y 3.5 to 6.5 each side of the centreline.
- At eject the yoke arms pass only 0.16 above the stand top over the rails, and the piston webs 0.55 above
  it inside: **the stand top must be one flat plane at the side plates' bottom edge, with nothing proud of it**
  (no weld beads, bolt heads or shims on top).
- Cross tubes at the fixed-pin end, under the lid end of the mold, and under the point where the open lid's
  ramps land (about 23.8 from the mold's fixed-pin end).

**Fabrication.**
1. Drill the two 9/16 foot clip holes in each rail's top wall: 3.5 and 12.5 from the rail's fixed-pin end,
   1.75 in from its inner face. The two rails are mirror images.
2. Weld the three cross tubes between the rails, tops flush, on a flat table. Grind the top welds flush.
3. Weld the legs under the outer half of the rails at the four corners and the foot plates under the legs.
4. Set the stand on the floor and shim the foot plates until both rails are level and in one plane;
   lag or anchor-bolt through the foot plates.
5. Bolt the press's foot clips down with the bolt heads under the rail top wall (nuts inside the tube).

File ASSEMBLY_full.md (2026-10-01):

# CINVA-Ram Block Press (heavy-duty version), 14 x 7 x 4 — Welding & Assembly Guide

> This is the guide for the heavy-duty press in `cinva_ram_b123d.py` (claw latch, eject roller on posts).
> The recommended press is the simpler permies-style one: see `ASSEMBLY.md`.

Fabrication sequence for the press in `drawings/14x7x4/` (drawing set `CR-14x7x4-00` to `-31`).
Part numbers below are the item numbers on the parts list (sheet 1). All dimensions in inches.

**How it works (read this first).** The piston slides in the mold box. Main pin **P** runs through
the piston webs, out through vertical slots in both side walls, and into the two **yoke bars**
outside the box. At the top, the yoke bars carry the **handle head** on two stub pins **Q**. A
saddle **roller** on the handle head rides a concave track on the **lid ribs**. Pulling the handle
from upright to just past horizontal lifts Q by 2.75, the yoke pulls the piston up, and the soil
is squeezed between the piston and the lid. The squeezing force runs through the brick, piston,
pin P, yoke, pins Q, roller and lid, **not through the frame or the welds of the mold box**. The
frame only guides. See sheet 3 for the four operating positions.

**Latch claw.** One claw in the middle of the press (two plates, item 20, joined by a thumb bar,
item 21) pivots on a tie (item 22) welded between horns on the tops of the yoke bars. It hooks a
catch bar (item 28) between the handle cheeks. Shut, it locks the handle to the yoke so handle and
yoke tip back and eject as one piece. The load runs straight along the claw, so it cannot pry it
open, and a counterweight tail behind the pivot keeps it shut under its own weight at every tilt. For
pressing, push the thumb bar down to flip the claw over (about 100) onto the stop rod (item 24); it stays
there.

## General welding rules

- Process: SMAW with E7018 or GMAW with ER70S-6. Fillet welds 1/4 unless noted.
- **AR400 lid ribs (item 10):** low-hydrogen only (E7018 from a rod oven, or ER70S-6),
  preheat the joint to 300 F, let cool slowly (cover with a welding blanket). Do not quench.
- **No weld, spatter or grinding marks inside the mold box or on the lid underside.** These
  surfaces form the brick. Weld outside only; grind any spatter flush and smooth.
- **Do not weld on any 4140 part** (items 18, 19, 22, 26, 27, 28) except where a note says so (claw
  tie into the yoke horns, catch bar and roller axle into the cheeks). Keep those welds small and let
  them cool slowly; 4140 cracks when welded hard and quenched.
- Keep heat away from pin holes. Where a hole crosses a welded joint (piston web pin hole), drill
  or line-bore it **after** welding.
- Tack everything, check it, then run final welds in short alternating passes to control distortion.

## Purchased and turned items

| Item | Part | Stock / spec | Qty | Notes |
|---|---|---|---|---|
| 18 | Main pin P | 1.750 round 4140 prehard, 11.500 long | 1 | Two 9/32 cross holes, 1/4 hitch pins |
| 19 | Stub pin Q | 1.500 round 4140 prehard, 2.562 long | 2 | Two 9/32 cross holes each |
| 21 | Claw thumb bar | 0.875 round 1018, 4.000 long | 1 | |
| 22 | Claw tie | 1.750 round 4140 prehard, 10.250 long | 1 | |
| 23 | Tie spacer | 2.500 OD 1018, 2.312 long, bore 1.812 | 2 | Loose on the tie |
| 24 | Claw stop rod | 0.750 round 1018, 10.250 long | 1 | |
| 26 | Saddle roller | 3.000 OD 4140, hardened 40-45 HRC, 7.000 long, bore 1.781 | 1 | Ream bore for a running fit |
| 27 | Roller axle | 1.750 round 4140 prehard, 8.625 long | 1 | |
| 28 | Catch bar | 1.500 round 4140 prehard, 8.625 long | 1 | |
| 6 | Eject roller | 3.000 OD 1045, 5.500 long, bore 1.062 | 1 | |
| 7 | Eject roller axle | 1.000 round 1018, 10.500 long | 1 | |
| 12 | Lid hinge pin | 0.750 round 1018, 1.750 long | 2 | Washers + 1/8 cotter pins |
| — | Hardware | 1/4 hitch pins (6), 1/8 cotter pins (4), 3/4 washers (4), 1/2 anchor bolts or lags (4) | | |
| — | Grease | general-purpose lithium grease for all pins and rollers | | |

Everything else is cut from plate, flat bar or tube. Use the DXF files in `drawings/14x7x4/dxf/`
for the plate profiles (1:1, inches); they match the drawings.

## Step 1 — Base frame (items 3, 4, 5, 6, 7)

1. Lay the two **base rails** (48.000, 3 x 2 x 3/16 tube, 3 tall) parallel on a flat table,
   7.750 apart centre to centre (outer faces 9.750 apart).
2. Weld the two **cross ties** between the rails, one flush with each end.
3. Check the frame is flat and square (diagonals equal within 1/16). Weld out.
4. Call the rail end with the short overhang the **front end**. Stand the two **eject roller posts**
   (2 x 2 x 1/4 tube) on the rails at the **back end**, centred on the rails, post centres 3.000 from
   the back end (45.000 from the front end). The axle holes must face each other across the frame.
5. Pass the **eject roller axle** through both posts with the **eject roller** on it, check it
   spins freely, then weld the posts to the rails, plumb both ways. Weld the axle ends to the
   posts (small tack welds) or retain with cotter pins.

## Step 2 — Mold box (items 1, 2)

The mold is 14.000 x 7.000 inside and 16.500 tall. Its inside must be square, smooth and
parallel; the brick quality depends on it.

1. Stand the two **side walls** (3/4 plate, slotted) on the table, slots facing each other and
   aligned: pass a 1.750 bar through both slots to check. The slots are at the middle of the
   14.000 length.
2. Fit the two **end walls** (5/8 plate, 8.500 wide) across the ends of the side walls, overlapping
   the side-wall ends, flush at top and bottom.
3. Clamp. Measure the inside: 14.000 x 7.000 at the top, middle and bottom. Diagonals equal within
   1/32. The top edges must be in one plane (the lid seals on them).
4. Tack the four outside corners top and bottom. Re-check square.
5. Weld the four vertical corner seams **outside only**, in short alternating runs.
6. Check the inside again and grind any high spots smooth.

## Step 3 — Mount the box and the hinge lugs (items 8)

1. Set the mold box on the base rails with the side walls centred on the rails and the inside face
   of the front end wall 8.000 from the front end of the rails. The mold centreline is then 15.000
   from the front end and 30.000 from the eject roller posts. The end wall nearest the posts is the
   **eject end**; the lid hinges there.
2. Weld the side-wall and end-wall bottom edges to the rails (outside only).
3. Weld the two **wall hinge lugs** to the outer face of the eject-end wall: top edge flush with
   the mold top, lug outer face 0.250 in from the side-wall outer face, hole 0.750 below the mold
   top and 0.750 out from the wall face. Pass a 3/4 rod through both lug holes to check alignment.

## Step 4 — Piston (items 14, 15, 16)

1. Lay the **piston cap** (3/4 plate, 13.875 x 6.875) face down.
2. Stand the two **piston webs** (1/2 plate, 8.750 tall) on it, flush with the long edges.
3. Fit the two **diaphragms** between the webs at the ends, flush with the cap ends.
4. Tack, check the webs are square to the cap, then weld the webs and diaphragms to the cap and to
   each other. Keep welds off the pin-hole area.
5. **Line-bore or drill the 1.781 pin hole through both webs together after welding**, centred on
   the length, 8.000 below the cap top face. Check with the 1.750 main pin.
6. Try the piston in the mold: it must slide freely the full height with about 1/16 clearance
   each side. Break the cap edges lightly. Do not weld the piston to anything.

## Step 5 — Lid (items 9, 10, 11, 13)

1. Mark the **lid plate** (1/2 plate, 15.250 x 8.500) centreline. Its underside is the top of the
   brick: keep it flat, clean and free of weld.
2. Stand the two **AR400 ribs** on the lid, 5.000 apart centre to centre (each 2.500 from the
   centreline), ends flush with the lid ends, the **lowest point of the track arc on the lid
   centre** (7.625 from each end). Both ribs must be identical: cut them together from the DXF.
3. Preheat to 300 F. Weld both sides of each rib full length with low-hydrogen filler. Slow-cool.
4. Check the tracks are straight, level with each other and square to the plate within 1/64.
   Dress the track arc smooth with a flap disc. **No flats or edges on the arc.**
5. Weld the two **lid hinge lugs** on top of the lid at the eject end: inner edge against the lid
   end face, lug outer face 0.750 in from the lid edge. The hinge hole sits below the lid, 0.750
   outside the lid end. The tail lobe points down toward the end wall.
6. Weld the **handle stop** (2 x 2 x 1/4 tube with 1/4 cap, 5.133 tall + cap) on the lid centreline,
   centred 1.625 from the lid end away from the hinge. Leave it slightly long; it is trimmed in step 8.

## Step 6 — Yoke and latch claw (items 17, 20 to 24)

1. Cut the two **yoke bars** from 3/4 plate using the DXF: a 3.000 wide bar with a **horn** beside
   the top hole (sheet 21). Clamp them together and drill all four holes through both at once so
   they match exactly: P 1.781 at the bottom, Q 1.531 at the top (19.500 above P), the tie hole
   1.781 in the horn (3.646 across and 0.847 above Q, toward the eject roller), and the stop-rod hole
   0.781 at the horn tip (5.853 across, 0.436 above Q).
2. Cut the two **claw plates** (3/4 plate) together from the DXF: pivot hole 1.781, notch for the
   1.500 catch bar 2.500 from the pivot, counterweight tail with the 0.906 thumb-bar hole. The notch
   side walls are arcs centred on the pivot hole; keep them as cut and dress them smooth.
3. Push the **thumb bar** through both claw plates, inside faces 2.500 apart, ends flush with the
   outside faces, and weld both ends. Check the two notches line up (lay the catch bar in both).
4. Weld the **claw stop rod** through the stop-rod holes of both yoke bars, flush outside. The two
   bars must stand parallel, 8.750 apart inside, holes aligned.
5. Slide the **claw tie** through one yoke bar, then a **tie spacer**, the claw (pivot holes), the
   second tie spacer and the other yoke bar. Weld the tie into both horns, flush outside (small
   welds, slow cool). The claw must swing freely on the tie.
6. The yoke is now one rigid frame: tie and stop rod across the top, pin P across the bottom.

## Step 7 — Handle head (items 25 to 31)

1. Cut the two **cheeks** (3/4 plate) as a pair and drill them clamped together: Q hole 1.531,
   roller hole 1.781 at 2.500 from Q, catch-bar hole 1.531 per sheet 29.
2. Set the cheeks up parallel, inner faces 7.125 apart, holes aligned (pass a bar through each hole pair).
3. Weld the plain **bridge** between the cheeks 5.750 from Q along the handle line, and the **bored
   bridge** at 8.500. The plain bridge sits above the claw's swing; do not move it closer to Q.
4. Slide the **handle tube** (1-1/2 sch 80, 65.500 long) through the bored bridge, butt it to the plain
   bridge, and weld at both bridges. The tube is on the handle line through Q.
5. Push the **catch bar** through both cheeks, flush outside, and weld it to each cheek.
6. Grease the bore of the **saddle roller**, hold it between the cheeks and push the **roller axle**
   through. Axle ends are flush with the cheek outer faces. Check the roller spins, then tack-weld the
   axle ends to the cheeks (keep it small and let it cool slowly).

## Step 8 — Final assembly

1. Drop the piston into the mold from the top, webs toward the side walls.
2. Hang the yoke frame outside the side walls, horns toward the eject roller, and push **main pin
   P** through yoke bar, side-wall slot, both piston webs, the other slot and the other yoke bar.
   Hitch pins in both cross holes.
3. Flip the claw open onto its stop rod. Set the handle head between the tops of the yoke bars and
   fit the two **stub pins Q** from the outside (through yoke bar and cheek). Hitch pins in both.
4. Stand the handle upright along the yoke and lift the thumb bar: the claw swings over and hooks the
   catch bar by itself.
5. Set the lid on the mold top and fit the two **hinge pins** through the lid and wall lugs, washers
   and cotter pins.
6. Grease all pins, the roller, the claw tie and the rib tracks.

## Step 9 — Adjust and test (empty)

1. **Lid:** lift the free end; the lid swings up about the eject-end hinge and must come to rest on
   its lug tails at about 100 (just past vertical). It must close flat on the mold top all round.
2. **Claw:** with the handle upright on the yoke, the claw must drop fully onto the catch bar by
   itself. Push the thumb bar down to flip it over: it must come to rest on the stop rod and stay there.
3. **Latch and tilt:** with the claw shut and the lid closed, tilt handle and yoke back until the
   handle rests on the eject roller. The claw must stay shut; nothing may touch the lid on the way.
4. **Stroke:** swing upright, flip the claw open, pull the handle over to horizontal and on down to
   the handle stop. The roller must roll the whole way on the track arc. Measure piston top to mold
   top with the handle horizontal: **4.000** (brick thickness). At the start it is 6.750.
5. **Stop height:** the handle must land on the stop about 3 past horizontal. Trim or shim the stop
   cap until it does. This sets the over-centre lock: past horizontal the brick pressure holds the
   handle down on the stop.
6. **Eject:** raise the handle upright, drop the claw onto the catch bar, tilt back onto the eject roller, open the lid, push the handle down. The piston
   top must come up 1/8 above the mold top.

## Step 10 — Load test before production

Make ten bricks with carefully measured fills (6.750 of loose mix, struck off level). Check:
thickness 4.000, corners sharp, no cracking, handle stays on the stop by itself, no permanent set in
the lid, pins or yoke bars. Measure the lid plate and pins against the drawings after the test.
**Never overfill:** the toggle multiplies force at lock-up and an overfilled mold can overload the
press (the parts are checked to 306 psi, about 30,000 lbf on the piston; see sheet 4).

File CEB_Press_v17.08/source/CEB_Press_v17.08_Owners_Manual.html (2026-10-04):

# CEB Press v17.08 Owner's Manual

From Open Source Ecology

Jump to navigation Jump to search

# CEB Press v17.08 Operation Manual

 1.1  CEB Press v17.08 Specifications
 1.2  CEB Press v17.08 Design + Function
 1.3  CEB Press v17.08 Startup Checklist 
 1.4  CEB Press v17.08 Safety Video
 1.5  CEB Press Operation, Safety, and Maintenance
 1.6  CEB Press Troubleshooting and Repair
 1.74 CEB Press User Agreement

# Power Cube v17.08 Operation Manual

Power Cube Operation and Safety - video
Power Cube Failure Modes and Troubleshooting
Power Cube Maintenance

# v17.08 Assets

CAD files, bills of materials, and other supporting information are found at CEB Press v17.08 and Power Cube v17.08.

Control code for the brick press is at File:Ceb17 08 v2.ino. This code can be uploaded via the Arduino software to the microcontroller via a USB to Mini B Cable.

Retrieved from "https://wiki.opensourceecology.org/index.php?title=CEB_Press_v17.08_Owner%27s_Manual&oldid=160001"

Category:

- Power Cube

## Navigation menu

### Search

- This page was last edited on 6 October 2017, at 06:59.
- Content is available under CreativeCommons by-sa4.0 unless otherwise noted.
- Privacy policy
- About Open Source Ecology
- Disclaimers
- Powered by MediaWiki (https://www.mediawiki.org/)

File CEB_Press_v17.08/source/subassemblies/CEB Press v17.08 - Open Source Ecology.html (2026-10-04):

# CEB Press v17.08

From Open Source Ecology

Jump to: navigation, search

## Contents

[hide]

- 1 Development Template
- 2 Controller
- 3 Solenoid Valve
- 4 Control Code
- 5 CAD
- 6 CAM
  - 6.1 Updated CNC Cut Files
- 7 BOM
- 8 Build Instructions
  - 8.1 Hydraulics + Controls
  - 8.2 Language Agnostic Instructionals - Structure
- 9 User Manual
- 10 CEB Press Upgrades 2017 - Working Docs on Redesign
- 11 Use
- 12 Cylinder Working Doc
- 13 Improvements and Future Work
  - 13.1 Optimizations
- 14 Team Needs
- 15 Advanced Soil Preparation Concept
- 16 Future Work
- 17 Links

# Development Template

[edit (https://docs.google.com/spreadsheets/d/1teVrReHnbS1xQFDJJhhmJX5_Lz2d5WkhJlq5yyeIfQw/edit#gid=1)]

# Controller

See CEB Press Controller v17.08 (https://wiki.opensourceecology.org/wiki/CEB_Press_Controller_v17.08)

# Solenoid Valve

edit (https://docs.google.com/presentation/d/1FlVSl3ECtCaX0mWZWkePI0iVrdmpKFGbgN5ryXN-2fI/edit)

# Control Code

See CEB Press Controller Genealogy (https://wiki.opensourceecology.org/wiki/CEB_Press_Controller_Genealogy) for previous versions.

- CEB_Press_Controller_Code_v17.08 (https://wiki.opensourceecology.org/wiki/CEB_Press_Controller_Code_v17.08)
- Ardublock (https://wiki.opensourceecology.org/wiki/Ardublock)

2017 version:

edit (https://docs.google.com/presentation/d/1rvL03pGooBHgqAsZgbIspqt-43aElZdl73FI9XaB430/)

# CAD

- Download FreeCAD source file at File:CEB 17.08 CAD Assembly.fcstd (https://wiki.opensourceecology.org/wiki/File:CEB_17.08_CAD_Assembly.fcstd).
- See also CEB Press Part Library (https://wiki.opensourceecology.org/wiki/CEB_Press_Part_Library) for individual parts.

# CAM

## Updated CNC Cut Files

- Master CAM File - File:CEB v1708 CAM.zip (https://wiki.opensourceecology.org/wiki/File:CEB_v1708_CAM.zip).
- There are pieces cut from eighth inch steel, quarter inch steel, and half inch steel - marked accordingly
- Broken line in 1/8" material is a bend line
- Numbers in brackets refer to the quantities
- Nesting in Master CAM file is on a 4'x8' sheet of steel
- Some of the individual files are File:CEB DXFs.zip (https://wiki.opensourceecology.org/wiki/File:CEB_DXFs.zip) - but a lot of them failed to import into LibreCAD (https://wiki.opensourceecology.org/wiki/LibreCAD).
- Steel order from Seaman and Schuske for only the 1/2" steel plate - nested onto 5x10 foot steel- File:Seamanandschuske.zip (https://wiki.opensourceecology.org/wiki/File:Seamanandschuske.zip)

# BOM

edit (https://docs.google.com/spreadsheets/d/13KNgqxBnRS74VeV-n_2zgx6M59SItwffWz9smh8bYoA/edit)

# Build Instructions

## Hydraulics + Controls

edit (https://docs.google.com/presentation/d/1T10bEJZG6I0Rlo8rbFQpf5rDuFQBssHSBFZ56fiFpmI/edit)

## Language Agnostic Instructionals - Structure

edit (https://docs.google.com/presentation/d/19H73tWsGTSAUAgM9OcMCg8zqXKYz7s7N05uYf6eSJt4/edit)

# User Manual

See CEB_Press_v17.08_Owner's_Manual (https://wiki.opensourceecology.org/wiki/CEB_Press_v17.08_Owner%27s_Manual)

# CEB Press Upgrades 2017 - Working Docs on Redesign

edit (https://docs.google.com/presentation/d/1Bf6_ZnNfEHmgzdF-keWcydmJ_EaT6IHgY6Hp7KbsfWo/edit)

edit (https://docs.google.com/presentation/d/1l6PDd9BekilVdvlw85jwtsPhCETmsJVfUnbR9R8ycto/edit)

# Use

v16.09 in use without hopper and with manual controls to allow workshop participants to operate the machine hands on:

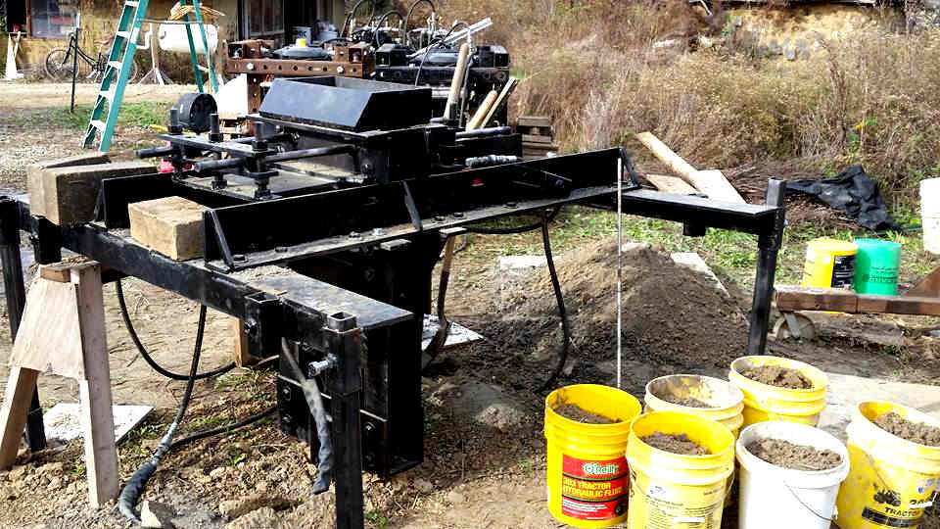
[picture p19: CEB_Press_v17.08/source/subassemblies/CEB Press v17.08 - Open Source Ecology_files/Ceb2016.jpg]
 (https://wiki.opensourceecology.org/wiki/File:Ceb2016.jpg)

# Cylinder Working Doc

CEB Cylinder (https://wiki.opensourceecology.org/wiki/CEB_Cylinder)

# Improvements and Future Work

Our machine nears perfection. Last year we developed a modular CEB controller that is made from common parts and CAT 5 quick connects from controller to solenoids. We have tested a stationary soil mixer last year. This year the several improvements include:

- Further Simplification of drawer guides
- Visual logic programming via Ardublock (https://wiki.opensourceecology.org/wiki/Ardublock)
- CNC torch table cutting with the D3D CNC Torch Table (https://wiki.opensourceecology.org/wiki/D3D_CNC_Torch_Table). We will do various test cuts to verify parts fit, though we will be outsourcing from our local fab shop so that we have a guaranteed parts set on hand.
- CNC-cut Power cube with the same frame design as the D3D (https://wiki.opensourceecology.org/wiki/D3D) frame.
- Open Source CEB Cylinder (https://wiki.opensourceecology.org/wiki/CEB_Cylinder). Hydraulic open source cylinder for serviceability . Cylinder sourcing has been problematic due to our specific requirements, so we will make our own from a kit, while starting to explore the 3D printability of cylinder seals.
- New brute force mixer/rock crusher that doses cement for full control and complete mixing of soil, going for commercially-viable block. The concept is just begun, full design is forthcoming.

## Optimizations

- Poka-yoke the grate frame sides
- Cut angle poka-yokes for the frame mid, bottom, top

# Team Needs

-  (https://wiki.opensourceecology.org/wiki/File:Check.png)CEB CAD upgrades - starting from data collection on last year's machine

# Advanced Soil Preparation Concept

CEB Soil Preparation Concept (https://wiki.opensourceecology.org/wiki/CEB_Soil_Preparation_Concept)

# Future Work

CEB Press Future Work (https://wiki.opensourceecology.org/wiki/CEB_Press_Future_Work)

# Links

- CEB Press Utah Log (https://wiki.opensourceecology.org/index.php?title=CEB_Press_Utah_Log&action=edit&redlink=1) - records of getting the CEB press up and running, and performance/usage logs.
- CEB Press Roadmap (https://wiki.opensourceecology.org/wiki/CEB_Press_Roadmap)
- CEB Press Genealogy (https://wiki.opensourceecology.org/wiki/CEB_Press_Genealogy)
- CEB Press Part Library (https://wiki.opensourceecology.org/wiki/CEB_Press_Part_Library)
- CEB Press v16.09 (https://wiki.opensourceecology.org/wiki/CEB_Press_v16.09)
- CEB Cylinder (https://wiki.opensourceecology.org/wiki/CEB_Cylinder) - 2017 considerations for source-ability
- CEB Soil Preparation Concept (https://wiki.opensourceecology.org/wiki/CEB_Soil_Preparation_Concept) - considerations for high quality stabilized block pressing
- Talk:CEB_Press_v17.08 (https://wiki.opensourceecology.org/wiki/Talk:CEB_Press_v17.08)

Retrieved from "https://wiki.opensourceecology.org/index.php?title=CEB_Press_v17.08&oldid=197727"

Category (https://wiki.opensourceecology.org/wiki/Special:Categories):

- CEB Press (https://wiki.opensourceecology.org/wiki/Category:CEB_Press)

## Navigation menu

### Personal tools

- Log in (https://wiki.opensourceecology.org/index.php?title=Special:UserLogin&returnto=CEB+Press+v17.08)
- Request account (https://wiki.opensourceecology.org/wiki/Special:RequestAccount)

### Namespaces

- Page (https://wiki.opensourceecology.org/wiki/CEB_Press_v17.08)
- Discussion (https://wiki.opensourceecology.org/wiki/Talk:CEB_Press_v17.08)

### Variants

### Views

- Read (https://wiki.opensourceecology.org/wiki/CEB_Press_v17.08)
- View source (https://wiki.opensourceecology.org/index.php?title=CEB_Press_v17.08&action=edit)
- View history (https://wiki.opensourceecology.org/index.php?title=CEB_Press_v17.08&action=history)

### More

### Search

(https://wiki.opensourceecology.org/wiki/Main_Page)

### Navigation

- Main page (https://wiki.opensourceecology.org/wiki/Main_Page)
- Website (http://opensourceecology.org/)
- Site Map (https://wiki.opensourceecology.org/wiki/Wiki_map)
- Wiki Instructions (https://wiki.opensourceecology.org/wiki/Wiki_instructions#Wiki_User_Account)
- Recent Wiki Changes (https://wiki.opensourceecology.org/wiki/Special:RecentChanges)
- Blog (http://opensourceecology.org/blog-2/)

### Open Source Ecology

- About OSE (https://wiki.opensourceecology.org/wiki/Open_Source_Ecology)
- Support OSE (https://wiki.opensourceecology.org/wiki/Support_Open_Source_Ecology)
- Contact Us (https://wiki.opensourceecology.org/wiki/Contact_us)
- Mailing List (https://wiki.opensourceecology.org/wiki/Ose-announce)
- In The News (https://wiki.opensourceecology.org/wiki/Open_Source_Ecology_News_Center)
- Events (https://wiki.opensourceecology.org/wiki/Open_Source_Ecology:Current_events)
- Discussion Forums (http://forum.opensourceecology.org/)
- FAQ (https://wiki.opensourceecology.org/wiki/FAQ)

### Tools

- What links here (https://wiki.opensourceecology.org/wiki/Special:WhatLinksHere/CEB_Press_v17.08)
- Related changes (https://wiki.opensourceecology.org/wiki/Special:RecentChangesLinked/CEB_Press_v17.08)
- Special pages (https://wiki.opensourceecology.org/wiki/Special:SpecialPages)
- Printable version (https://wiki.opensourceecology.org/index.php?title=CEB_Press_v17.08&printable=yes)
- Permanent link (https://wiki.opensourceecology.org/index.php?title=CEB_Press_v17.08&oldid=197727)
- Page information (https://wiki.opensourceecology.org/index.php?title=CEB_Press_v17.08&action=info)
- This page was last edited on 1 September 2019, at 17:41.
- Content is available under CreativeCommons by-sa4.0 (https://wiki.opensourceecology.org/wiki/Copyright) unless otherwise noted.
- Privacy policy (https://wiki.opensourceecology.org/wiki/Open_Source_Ecology:Privacy_policy)
- About Open Source Ecology (https://wiki.opensourceecology.org/wiki/Open_Source_Ecology:About)
- Disclaimers (https://wiki.opensourceecology.org/wiki/Open_Source_Ecology:General_disclaimer)
CreativeCommons by-sa4.0
-  (https://creativecommons.org/licenses/by-sa/4.0/)
- Powered by MediaWiki (https://www.mediawiki.org/)

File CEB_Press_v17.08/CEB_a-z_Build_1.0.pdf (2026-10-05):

# CEB

# Complete Fabrication Instructions, 2011

# Open Source Ecology

## Compiled by Brianna Kufa

CEB Introduction

# CEB Introduction

The purpose of this guide is to provide all information to make the 2011 version CEB Press from stock steel and parts. More information, and a constantly updated procedure can be found on the OSE wiki CEB Manufacturing page. (http://opensourceecology.org/wiki/CEB_Press/Manufacturing_Instructions)

This guide is broken into 3 main fabrication steps: Mechanical Fabrication, Electronic Components, and Machine Integration. The steps in Mechanical Fabrication and Electronic Components are independent of each other, but within each category, the suggested order should be followed. Once both are finished, you the machine’s mechanical and electronic components can be integrated. At that point, your machine can be used.

Mechanical Fabrication begins with the cutting of all stock steel. After that, it is broken into two sections: Parts Fabrication, and Parts Assembly. Parts fabrication focuses on cutting, drilling, punching, bolting and welding the steel into individual parts, and is organized by machine systems. Parts assembly joins all of the sub-parts into the whole machine. To complete mechanical fabrication, the machine must be painted.

This video offers good insight on how to do many of the steps in assembly. Some steps will vary though. The written instructions are correct.

The Electronic Components section covers preparing all of the components which automate the machine. It requires the preparation of the machine sensors, and all of the components which reside in the controller box.

Machine Integration links the hydraulic, mechanical, and electrical components into a functioning CEB.

## Table of Contents

Frame U-Channel Assembly | 43
Fit the Main Cylinder | 47
Stretching the Frame | 50
Welding the Spacers | 51
Installing the Small Components | 52
Fit the Drawer Members | 54
Secondary Cylinder Hydraulics Preparation | 56
Parts Assembly | 57
Structural Components | 57
Soil Loading System | 59
Shaker | 63
Adjusting the Drawer | 65
Installing the Secondary Cylinder | 68
Hardlining the Main Cylinder | 71
Paint | 72
Electronic Components | 73
Linked Extension Cord | 73
Sensor Unit | 74
Solenoid Driver | 75
Case | 77
Controller Box | 79
Machine Integration | 81
Mount Solenoid Valve Set and Controller Box | 81
Electrohydraulic Integration | 83
Code Upload | 85

CEB Bill of Materials

# CEB Bill of Materials

## Steel

Type | Size | Total (inches) | Total (feet)
Angle | .25x2x2 | 291 | 24.25
Angle | .5x4x4 | 105 | 8.75
Angle | .5x4x6 | 288 | 24
Angle | .5x4x7 | 12 | 1
C-Channel | 3 | 3 | 0.25
C-Channel | 6 heavy | 274 | 22.83333333
DOM Round | 1.5 | 14.5 | 1.208333333
Dom tubing | 1.5 ID 2.0OD | 3 | 0.25
Flat | .25x1 | 14 | 1.166666667
Flat | .25x2 | 71.5 | 5.958333333
Flat | .1875x2.5 | 72 | 6
Flat | .25x3 | 6 | 0.5
Flat | .25x6 | 27 | 2.25
Flat | .25x7 | 27 | 2.25
Flat | .25x8 | 44.5 | 3.708333333
Flat | .375x 3 | 51 | 4.25
Flat | .5x2 | 72 | 6
Flat | .5x3 | 93.5 | 7.791666667
Flat | .5x6 | 12 | 1
Flat | 1/8x3 | 288 | 24
Flat | 1x1 | 5 | 0.416666667
Flat | 1x2 | 11 | 0.916666667
Flat | 1x4 | 10 | 0.833333333
Flat | 1x6 | 12 | 1
Flat | 1x7 | 12 | 1
Pipe | .75ID 1OD | 2 | 0.166666667
Rebar | 0.375 | 9 | 0.75
Rebar | 0.5 | 1122 | 93.5
Rebar | 1 | 14 | 1.166666667
Round | 1 | 7.25 | 0.604166667
Threaded Rod | 0.75 | 40.75 | 3.395833333
Tubing | .1875x2.5x2.5 | 84 | 7
Tubing | .25x2x2 | 288 | 24
Tubing | .5x6x6 | 12 | 1
Sheet | 1/8"x5'x10' | 1 full sheet
| 1/8"x5'x23.5" | Part of a sheet.

CEB Bill of Materials

## Fasteners

Description | Quantity
Bolt, HHCS, 0.313"-18x0.625"x0.625" | 8
Bolt, HHCS, 0.375"-16x2"x2" | 4
Bolt, HHCS, 0.5"-13x1"x1" | 16
Bolt, HHCS, 0.5"-13x2"x1.25" | 5
Bolt, HHCS, 0.5"-13x4"x4" | 2
Bolt, HHCS, 0.75"-10x1.5"x1.5" | 9
Bolt, HHCS, 0.75"-10x2"x2" | 34
Bolt, HHCS, 0.75"-10x2"x2" | 19
Bolt, HHCS, 0.75"-10x2.5"x2.5" | 6
Bolt, HHCS,0.75"-10x3"x3" | 6
M12 Bolt, Modified- 55mm | 4
Bolt, HHCS, 0.25"x2" | 1
B18.2.4.1M - Hex nut, Style 1, M12 x 1.75-D-C | 4
Nut, Hex, 0.375"-16 | 4
Nut, Hex, 0.5"-13 | 24
Nut, Hex, 0.75"-10 | 77
Nut, Hex, Steel, 0.75"x10 | 12
Nut, Hex, .25"-16, Lock | 1
Washer, Plain, Narrow, B18.22.M, 12mm | 4
Washer, Wide, 0.375" | 8
Washer, Wide, 0.5" | 28
Washer, Wide, 0.75" | 74
Washer, Lock, 0.25" | 1

## Hydraulics

Type | Item | Qty. | Source
Cylinder | 5x12x2.5
| Crosstube | 1 | https://www.surpluscenter.com/item.asp?item=9-1143-
| | | 12&catname=hydraulic
| 2.5x14x1.125
| Clevis | 1 | https://www.surpluscenter.com/item.asp?catname=hydraulic&qty=1
| | | &item=9-7619-14
Motor | Dynamic
| Hydraulic Motor | 1 | https://www.surpluscenter.com/item.asp?item=9-7077-
| | | 50&catname=hydraulic
Hoses | 1/4"x12" NPTM | 1 | https://www.surpluscenter.com/item.asp?item=916-
| | | 1412&catname=hydraulic
| 1/2"x36" NPTM | 3 | https://www.surpluscenter.com/item.asp?item=905-
| | | 1236&catname=hydraulic
| 1/2"x56" NPTM | 2 | https://www.surpluscenter.com/item.asp?item=905-
| | | 1260&catname=hydraulic

CEB Bill of Materials

Type | Item | Qty. | Source
Valves | 1/2" NPT Needle
| Valve | 1 | http://www.surpluscenter.com/item.asp?item=9-7960-
| | | 8&catname=hydraulic (http://www.surpluscenter.com/item.asp?item=9-7960-8&catname=hydraulic)
| 1/2" Flow
| Control and
| Relief Valve | 1 | https://www.surpluscenter.com/item.asp?item=9-064-
| | | 50&catname=hydraulic (https://www.surpluscenter.com/item.asp?item=9-064-50&catname=hydraulic)
| 1/2" NPTF Check
| Valve | 1 | https://www.surpluscenter.com/item.asp?item=9-7933-8-
| | | 5&catname=hydraulic (https://www.surpluscenter.com/item.asp?item=9-7933-8-5&catname=hydraulic)
Fittings | SAE 4M to 1/4"
| NPTF Swivel | 1 | https://www.surpluscenter.com/item.asp?item=9-6900-4-4-
| | | S&catname=hydraulic (https://www.surpluscenter.com/item.asp?item=9-6900-4-4-S&catname=hydraulic)
| SAE 6M to 1/2"
| Swivel | 6 | https://www.surpluscenter.com/item.asp?item=9-6900-6-
| | | 8&catname=hydraulic (https://www.surpluscenter.com/item.asp?item=9-6900-6-8&catname=hydraulic)
| SAE 12M to 3/4"
| Swivel | 2 | https://www.surpluscenter.com/item.asp?catname=&qty=1&item=9
| | | -6900-12-12 (https://www.surpluscenter.com/item.asp?catname=&qty=1&item=9-6900-12-12)
| 3/8" NPT Hex
| Nipple | 2 | http://www.surpluscenter.com/item.asp?item=9-
| | | 7184&catname=hydraulic (http://www.surpluscenter.com/item.asp?item=9-7184&catname=hydraulic)
| 1/2" NPT Hex
| Nipple | 6 | https://www.surpluscenter.com/item.asp?item=9-5404-8-
| | | 8&catname=hydraulic (https://www.surpluscenter.com/item.asp?item=9-5404-8-8&catname=hydraulic)
| 1/2" NPTM to
| 1/4" NPTF
| bushing | 1 | https://www.surpluscenter.com/item.asp?item=9-5406-8-
| | | 4&catname=hydraulic (https://www.surpluscenter.com/item.asp?item=9-5406-8-4&catname=hydraulic)
| 1/2" NPT to 3/8"
| NPT bushing | 2 | http://www.surpluscenter.com/item.asp?item=9-5406-8-
| | | 6&catname=hydraulic (http://www.surpluscenter.com/item.asp?item=9-5406-8-6&catname=hydraulic)
| 3/4" to 1/2" NPT
| Bushing | 2 | https://www.surpluscenter.com/item.asp?item=9-5406-12-
| | | 8&catname=hydraulic (https://www.surpluscenter.com/item.asp?item=9-5406-12-8&catname=hydraulic)
| 1/2" NPTM to
| 1/2" NPTF 90
| Elbow | 3 | https://www.surpluscenter.com/item.asp?item=9-5502-8-
| | | 8&catname=hydraulic (https://www.surpluscenter.com/item.asp?item=9-5502-8-8&catname=hydraulic)
| 1/2" NPTM
| Elbow | 2 | https://www.surpluscenter.com/item.asp?item=9-5500-8-
| | | 8&catname=hydraulic (https://www.surpluscenter.com/item.asp?item=9-5500-8-8&catname=hydraulic)
| 1/2" NPTF Tee | 2 | https://www.surpluscenter.com/item.asp?item=9-5605-8-8-
| | | 8&catname=hydraulic (https://www.surpluscenter.com/item.asp?item=9-5605-8-8-8&catname=hydraulic)
| 1/2" Quick
| Coupler Pair | 5 | https://www.surpluscenter.com/item.asp?item=928&catname=hydr
| | | aulic (https://www.surpluscenter.com/item.asp?item=928&catname=hydraulic)
| 3/4" Quick
| Coupler pair | 1 | https://www.surpluscenter.com/item.asp?item=928-
| | | C&catname=hydraulic (https://www.surpluscenter.com/item.asp?item=928-C&catname=hydraulic)

Solenoid

Daman Manifold
AD05S033S or
Dalton part#
240-712 | 1

Call Dalton to order
http://stores.daltonhydraulic.com/StoreFront.bok

CEB Bill of Materials

Solenoid Valve
for motor Type
H, Dalton Part #:
240-241 | 1

http://stores.daltonhydraulic.com/-strse-675/Solenoid-Directional-Control-Valve%2C/Detail.bok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 (http://stores.daltonhydraulic.com/-strse-675/Solenoid-Directional-Control-Valve%2C/Detail.bok)

Solenoid Valve
for rams Type C,
Dalton Part #:
240-244 | 2

http://stores.daltonhydraulic.com/-strse-674/Solenoid-Directional-Control-Valve%2C/Detail.bok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 (http://stores.daltonhydraulic.com/-strse-674/Solenoid-Directional-Control-Valve%2C/Detail.bok)

## Other

Description | Quantity | Source
Generic Door Hinge | 12 | Home depot
1" Keyed Coupler | 1 | https://www.surpluscenter.com/item.asp?item=1-1563-
| | E&catname=powerTrans (https://www.surpluscenter.com/item.asp?item=1-1563-E&catname=powerTrans)
12mm x 3mm N42
Epoxy Coated Disc Magnet | 6 | http://www.gaussboys.com/ndfeb-magnets/D1203E-N42.html

Pillow Block

Bearing - 1" | 2 | https://www.surpluscenter.com/item.asp?item=1-205-16-P-
| | C&catname=powerTrans
V-Groove Bearing | 4 | http://www.vxb.com/page/bearings/PROD/Kit8406

Power Clamps, AKA
Hose Clamps- 1” Max OD | 4 | Automotive Store, see
| | http://opensourceecology.org/wiki/File:Hose_Clamps.jpg

## Electronics

Item | Qty. | Source | Notes
50ft 16AWG Extension Cord | 1 | Electronics Store | http://opensourceecology.org/wiki/File:50ft3Wir
| | | e16AWGExtensionCord.jpg
Pair of Large Alligator Clips
(Black and Red) | 1 | Electronics Store | http://opensourceecology.org/wiki/File:Alligator
| | | Clips.jpg
Female Insulated Connector
16-22AWG | 1 | Electronics Store | http://opensourceecology.org/wiki/File:FemaleIn
| | | sulated16to22AWGConnector.jpg
Outdoor Main Lug Box | 1 | Hardware Store | http://opensourceecology.org/wiki/File:LugBox.p
| | | ng
Wire Clamps | 2 | Hardware Store | http://opensourceecology.org/wiki/File:WireCla
| | | mps.jpg
Toggle Switch | 1 | Hardware Store | http://opensourceecology.org/wiki/File:ToggleS
| | | witch.jpg
Washer 1.25" OD .5" ID | 2 | Hardware Store | http://opensourceecology.org/wiki/File:Washer1
| | | -25OD0-5ID.jpg

CEB Bill of Materials

Fuse Holder | 1 | Electronics Store | http://opensourceecology.org/wiki/File:FuseHold
| | | er.jpg
Male Insulated Connector
10-12AWG | 1 | Electronics Store
Ring Insulated Connector
Small Hole 10-12AWG | 2 | Electronics Store
Buss Fuse 10Amp | 1 | Electronics Store | http://opensourceecology.org/wiki/File:10ABuss
| | | Fuse.jpg
Ring Insulated Connector
10-12AWG | 20 | Electronics Store
12cm by 7.5cm by 0.4cm
HDPE Plate
(4.75"x3"x5/32") | 2 | Hardware Store
M3 20mm Machine Screws | 4 | Hardware Store
M3 Nylon-threaded
Locknuts | 4 | Hardware Store
8-32 machine screws of 3/8
inch length | 7 | Hardware Store
8-32 machine screws of ¾
inch length | 4 | Hardware Store
Arduino Uno
Microcontroller | 1 | Digikey | http://www.digikey.com/1/parts/2412553-
| | | arduino-uno-board-a000046.html
Underground Telephone
Wire (4-wire) 3m length 1
Shrink Tubing 16-22AWG
18cm length | 1 | Electronics Store
Hall Effect Sensor | 2 | Digikey | http://www.sparkfun.com/products/9312
PVC Pipe with 1" Outer
Diameter, 9/16" Inner
Diameter, 3.5" Length | 2 | Hardware Store
Silicone 250ml | 1 | Hardware Store | Transparent Silicone Caulking
Ring Insulated Connector
14-16AWG | 20
Red Wire 18AWG 25ft | 1 | Electronics Store
Black Wire 18AWG 25ft | 1 | Electronics Store

CEB Bill of Materials

## Solenoid Driver –

Note: this is included separately from electronics in case you choose to make a different driver board.

Description | Qty. | Source

http://search.digikey.com/scripts/DkSearch/dksus.dll?Detail&name=RFD16N05
Power N MOSFET | 5 | LSM9ACT-ND (http://search.digikey.com/scripts/DkSearch/dksus.dll?Detail&name=RFD16N05LSM9ACT-ND)
http://search.digikey.com/scripts/DkSearch/dksus.dll?Detail&name=160-1169-
Green LED | 7 | 1-ND (http://search.digikey.com/scripts/DkSearch/dksus.dll?Detail&name=160-1169-1-ND)
http://search.digikey.com/scripts/DkSearch/dksus.dll?Detail&name=641-1331-
Diode | 5 | 1-ND (http://search.digikey.com/scripts/DkSearch/dksus.dll?Detail&name=641-1331-1-ND)
http://search.digikey.com/scripts/DkSearch/dksus.dll?Detail&name=311-
499 Resistor | 5 | 499FRCT-ND (http://search.digikey.com/scripts/DkSearch/dksus.dll?Detail&name=311-499FRCT-ND)
http://search.digikey.com/scripts/DkSearch/dksus.dll?Detail&name=311-
49.9k Resistor | 5 | 49.9KFRCT-ND (http://search.digikey.com/scripts/DkSearch/dksus.dll?Detail&name=311-49.9KFRCT-ND)
http://search.digikey.com/scripts/DkSearch/dksus.dll?Detail&name=311-
10k Resistor | 2 | 10.0KFRCT-ND (http://search.digikey.com/scripts/DkSearch/dksus.dll?Detail&name=311-10.0KFRCT-ND)
http://search.digikey.com/scripts/DkSearch/dksus.dll?vendor=0&keywords=ED
2 Pos Terminal | 9 | 1514-ND (http://search.digikey.com/scripts/DkSearch/dksus.dll?vendor=0&keywords=ED1514-ND)
http://search.digikey.com/scripts/DkSearch/dksus.dll?Detail&name=SW262CT-
reset switch | 1 | ND (http://search.digikey.com/scripts/DkSearch/dksus.dll?Detail&name=SW262CT-ND)
http://search.digikey.com/scripts/DkSearch/dksus.dll?vendor=0&keywords=a1
6 Pos Header | 2 | 913-nd (http://search.digikey.com/scripts/DkSearch/dksus.dll?vendor=0&keywords=a1913-nd)
http://search.digikey.com/scripts/dksearch/dksus.dll?pname&site=us&lang=en
8 Pos Header | 2 | &WT.z_cat_cid=Dxn_US_US2011_Catlink&name=A1914-ND (http://search.digikey.com/scripts/dksearch/dksus.dll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)
http://search.digikey.com/scripts/DkSearch/dksus.dll?Detail&name=473-1002-
PCB | 1 | ND (http://search.digikey.com/scripts/DkSearch/dksus.dll?Detail&name=473-1002-ND)
http://search.digikey.com/scripts/DkSearch/dksus.dll?Detail&name=311-
100 Resistor | 2 | 100FRCT-ND (http://search.digikey.com/scripts/DkSearch/dksus.dll?Detail&name=311-100FRCT-ND)

CEB Cut List

# CEB Cut List

Cut the steel into the following lengths. Label and separate cuts by "Step" number so you can easily find cuts for each step during the fabrication stage. The step number for each sub-guide is listed in parenthesis in the upper left corner in the header.

Type | Size (") | Length
| | (") | Qty | Primary Part Name | Secondary Part Name | Step #
Angle | .25x2x2 | 6 | 2 | Main Frame | Dirt Blockers | 17
| | 6 | 2 | Wide cylinder support | | 12
| | 10 | 2 | Soil Shaker | Side of guard | 3
| | 16 | 2 | Soil Shaker | top and bottom of guard | 3
| | 35.5 | 2 | Soil Grate | | 9
| | 72 | 2 | Soil Grate | | 9
Angle | .5x4x4 | 8 | 1 | Soil Shaker | | 3
| | 21 | 1 | Soil Shaker | | 3
| | 38 | 2 | Grate supports | | 6
Angle | .5x4x6 | 72 | 2 | Secondary Arms | | 2
| | 72 | 2 | Primary Arms | | 2
Angle | .5x4x7 | 12 | 1 | Soil Loading Drawer | Back | 10
C-Channel | 3 | 1.5 | 2 | Main Frame Small
| | | | Components | Thin Cylinder support | 13
C-Channel | 6 heavy | 13 | 2 | Main Frame | Spacers | 17
| | 21 | 4 | Main Frame | Horizontal Members | 14
| | 29 | 2 | Wide cylinder support | | 12
| | 53 | 2 | Main Frame | Vertical Members | 14
DOM
Round | 1.5 | 3.5 | 1 | Main Cylinder | Fill in rod tubing | 16
| | 11 | 1 | Main Frame | Cylinder Pin | 18
Dom tubing | 1.5 ID
| 2.0OD | 1.5 | 2 | Main Frame | Horizontal Members,
| | | | | cylinder mounting | 18
Flat | .1875x2.5 | 36 | 2 | Soil Loading Drawer | Outer Rails | 10
Flat | .25x1 | 14 | 1 | Main Frame Small
| | | | Components | Magnet Holder | 13
Flat | .25x2 | 12 | 1 | Controller Mount | | 1
| | 71.5 | 1 | Soil Grate | Cross piece | 9
Flat | .25x3 | 6 | 1 | Controller Mount | Bottom piece | 1
Flat | .25x6 | 12 | 1 | Valve Mount | | 1
| | 15 | 1 | Controller Mount | | 1
Flat | .25x7 | 13.5 | 2 | Soil Loading Drawer | Sides | 10
Flat | .25x8 | 8 | 4 | Feet | | 2
Flat | .25x8 | 12.5 | 1 | Soil Loading Drawer | Roof | 10
Flat | .375x 3 | 24 | 2 | Main Frame | Horizontal Members
| | | | | Reinforcement | 17

CEB Cut List

| | 3 | 1 | Roller Guides | Spacer Plate | 11
Flat | .5x2 | 36 | 2 | Soil Loading Drawer | Inner Rails | 10
Flat | .5x3 | 3 | 1 | Secondary arms | Eye for 2nd cyl | a5
| | 3 | 1 | Soil Loading Drawer | Tongue | 10
| | 11.25 | 2 | Hopper Mounting
| | | | Plate | | 8
| | 15 | 2 | Hopper Mounting
| | | | Plate | | 8
| | 16 | 2 | Roller Guides | Main Plate | 11
Flat | .5x6 | 12 | 1 | Soil Loading Drawer | Vertical Supports | 10
Flat | 1/8x3 | 36 | 8 | Hopper Sheet Metal | Hinge Plates | 7
Flat | 1x1 | 2.5 | 2 | Preparing the Main
| | | | Cylinder | Press foot supports | 16
Flat | 1x2 | 5 | 1 | Soil Shaker | Hammer | 4
| | 6 | 1 | Soil Shaker | Hammer | 4
Flat | 1x4 | 10 | 1 | Preparing the Main
| | | | Cylinder | Lower Press Foot | 15
Flat | 1x6 | 12 | 1 | Preparing the Main
| | | | Cylinder | Upper Press foot | 15
Flat | 1x7 | 12 | 1 | Soil Loading Drawer | Press Plate | 10
Pipe | .75ID 1OD | 1 | 2 | Main Frame Small
| | | | Components | Thin Cylinder support | 13
Rebar | 0.375 | 3 | 1 | Main Frame Small
| | | | Components | Sensor Holder | 13
| | 6 | 1 | Main Frame Small
| | | | Components | Sensor Holder | 13
Rebar | 0.5 | 34 | 33 | Soil Grate | | 9
Rebar | 1 | 7 | 2 | Soil Shaker | | 3
Round | 1 | 7.25 | 1 | Soil Shaker | | 4
Threaded
Rod | 0.75 | 1.25 | 1 | Main Frame Small
| | | | Components | Magnet Holder | 13
| | 3.5 | 1 | Main Frame Small
| | | | Components | Sensor Holder | 13
| | 3.5 | 1 | Main Frame Small
| | | | Components | Sensor Holder | 13
| | 6.25 | 2 | Main Frame Small
| | | | Components | Thin Cylinder support | 13
| | 3.75 | 4 | Main Frame | Drawer member drawer
| | | | | adjuster bolts | 14
| | 2.5 | 2 | Main Cylinder | Upper Press foot | 15
Tubing | .1875x2.5x
| 2.5 | 6 | 14 | Leg Holders | | 2
Tubing | .25x2x2 | 48 | 4 | Legs | | 2
| | | 2 | Hopper Supports | | 6
Tubing | .5x6x6 | 12 | 1 | Soil Loading Drawer | Spacer | 10
| 6x12 | 50 | 1 | Optional Jig for Main
| | | | Frame Assembly | | 17

CEB Cut List

1/8” sheets, to be torched:
- After torching, grind the edges smooth. Full sheet:

Partial Sheet:

CEB Simple Plates (1)

# CEB Simple Plates

See the Sketchup Model.

Tools Needed:
- Hole Puncher
- Drill Press
- Center Punch
- Hammer
- Welder

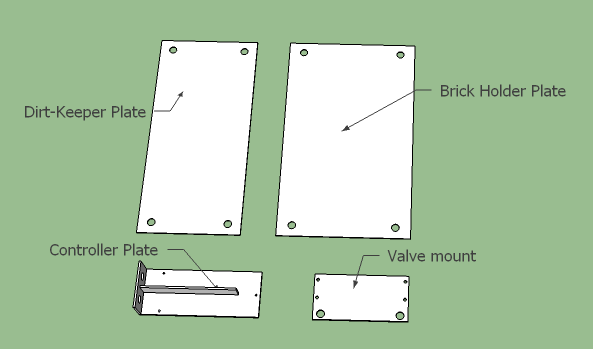
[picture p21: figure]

## Brick holder Plate, Dirt Keeper Plate, Valve Mount

Punch or drill the holes as shown.

Materials Needed:
- 1/8” Sheet- 17.5”x29” Brickholder Plate
- 1/8” Sheet- 13.5”x29” Dirt-Keeper Plate
- ¼”x6” Flat- 12” Valve Mount
- ¼”x6” Flat- 15” Controller Mount
- ¼”x3” Flat- 6” Controller Mount
- ¼”x2” Flat- 12” Controller Mount

CEB Simple Plates (1)

## Controller Plate

1. Find your controller box (also called outdoor main lug box) and locate its mounting holes on the back.
2. Place it on top of the 6x15 plate so it is square and the top hole is about ½” away from the top. Transfer punch the holes on the controller box to the plate.
3. Drill those as ¼” holes.
4. Punch the holes in the bottom piece.
5. Weld the bottom piece to the large plate. Make sure it is square.
6. Weld the 1/4"x2 to the back as well.

CEB Frame Structural Support Components (2)

# CEB Frame Structural Support Components

This section covers:
- Leg Holders-Model (http://sketchup.google.com/3dwarehouse/details?mid=9ede5ca4cc4cd2301211da1f85706ccd)
- Feet- Model (http://sketchup.google.com/3dwarehouse/details?mid=9cd8c14e87d341971211da1f85706ccd)
- Legs- Model (http://sketchup.google.com/3dwarehouse/details?mid=46674851ee0302a11211da1f85706ccd) | • Welder (http://makeprojects.com/Item/Welder)
- Secondary Arms- Model (http://sketchup.google.com/3dwarehouse/details?mid=4c317c20fdb7bac61211da1f85706ccd) | • Hole (http://makeprojects.com/Item/hole_puncher) Puncher
- Primary Arms- Left Primary Arm Model, (http://sketchup.google.com/3dwarehouse/details?mid=e9575044ab22492a1211da1f85706ccd) | • Torch (http://makeprojects.com/Item/torch)
- Right Primary Arm Model (http://sketchup.google.com/3dwarehouse/details?mid=c3bd225ffa19896e1211da1f85706ccd)

## Leg Holders

- You will need 14 Leg Holders for the CEB. 12 will be used in this section. Save the remaining ones for later. Make all leg holders at once to save time.
- These require:
- 3/16”x2.5”x2.5” square tubing- 6” (14)
- ¾” Steel Nuts (14)
- ¾”x1.5” Bolts (14)

## Feet

- You need to make 4 of these.
- These require:
- Leg Holders (4)
- ¼”x 8” Plate- 8” (4)
1. Center a leg holder on the ¼”x8”x8” plate, insuring it is square in all

directions.

2. Weld it 100% to the plate.
1. Torch a 3/4” hole in the center of one of the faces of the tubing; make sure it's large enough for a 3/4” bolt.
- It's not crucial that the hole be centered. It just needs to be somewhere close to the center.
2. Weld the nut over the hole, ensuring the nut is level, and the hole is clear.
3. Make sure no spatter goes into the threads by covering the top of the nut.
4. Thread the bolt onto the nut.

Tools Needed:
- Angle grinder (http://makeprojects.com/Item/Angle_grinder)
- Speed Square (http://makeprojects.com/Item/Speed_Square)

## Secondary Arms

CEB Frame Structural Support Components (2)

- These require:
- Leg Holders (4)
- ½”x4”x6” Angle- 72” (2)
1. Punch the 3/4" holes
2. Place the leg holders in their proper locations.
- Make sure they are square with the angle iron and centered vertically.
3. Weld them to the angle.

## Primary Arms

- These require:
- ½”x4”x6” Angle- 72” (2)
1. Punch all holes.
2. Label each arm with either "right" or "left."

CEB Frame Structural Support Components (2)

## Legs

- These require:
- ¼”x2”x2” Square tubing- 48” (4)
- There are no steps for these, just cut them.

CEB Shaker – Mount (3)

# CEB Shaker – Mount

Sketchup Model (http://sketchup.google.com/3dwarehouse/details?mid=dc44b08378d3b1441211da1f85706ccd)

Tools Needed:
- Angle Grinder
- Welder
- Hole Puncher
- Torch

## The Guard

1. Torch the guard sheet metal as in the image.
- Note: the shape
shown is centered.
2. Weld the top and side 2x2 angle pieces to it as shown.

Materials Required:
- ¼”x2”x2” Angle- 10” (2) Sides of Guard
- ¼”x2”x2” Angle- 16” (2) Top and Bottom of Guard
- 1/8”x10”x16” Sheet- (1) Guard
- ½”x4”x4” Angle-(1) 8”
- ½”x4”x4” Angle- (1) 21”
- 1” Rebar- 7” (2) Braces

## Mount Base

CEB Shaker – Mount (3)

1. Punch the holes in the 4x4 angle.
- Not all holes will be accessible with a punch. Torch the rest.

21” Angle

8” Angle

CEB Shaker – Mount (3) | 17

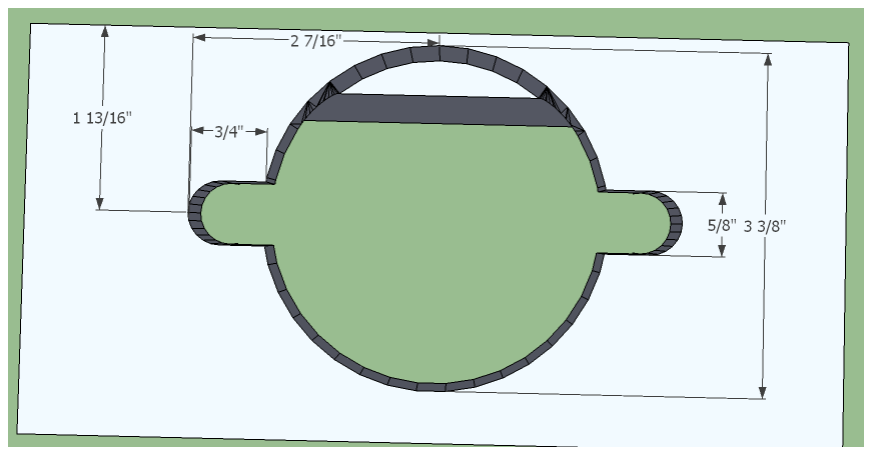
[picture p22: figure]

### 2. Torch the hole for mounting the motor in the 8"

piece of 4x4 angle. Grind off the slag.
- Double check that the hole is large enough by putting on the motor and making sure the raised portion in the center goes all the way thru.
- You can torch separate holes for the bolts, or do one large, odd shaped one like is pictured.

### 3. Weld it together

- Weld the bottom 2x2 to the 21" 4x4.
- Weld the two 4x4 angle pieces together as pictured, insuring they are perfectly flush and square.
- Skip around while welding so it doesn't warp one way or
another.
- Grind off the top weld linking the 4x4's so the bearing will be able to sit flush on it
- Also grind off near the bolt holes on the bottom.
- Weld the guard and braces to the mount.

CEB Shaker - Hammer and Shaft (4)

# CEB Shaker - Hammer and Shaft

Sketchup Model (http://sketchup.google.com/3dwarehouse/details?mid=a1af76b0b849ac2e1211da1f85706ccd)

Tools Needed:
- Welder
- Something to mark steel with
- Drill Press
- Hole puncher

### 1. Prepare the hammer

1. Drill or punch the hole in the flatbar.
2. Weld the two pieces of flatbar together
- This needs to be a really strong weld! The hammer will be under a lot of stress, and if it's not a solid weld, it could fly off! (This is why the guard is there).
3. Tack the shaft into the hole so there's about a 1/4" distance between the end of the shaft and the opposite side of the hammer.

Materials Required:
- 1”x2” Flat- 6” (1) Hammer
- 1”x2” Flat-5” (1) Hammer
- 1” Round- 7.25” (1) Shaft
- 1” Keyed Coupler (1)
- ¼”x2” Bolt (1)
- Shaker Motor
- Shaker Mount

CEB Shaker - Hammer and Shaft (4)

### 2. Couple the shaft

1. Cut the coupler down so it's 2" long. It doesn't matter from which side you cut it.
2. Get the shaker motor, the mount you made, the shaft/hammer, and the coupler.
3. Put the shaker motor onto the mount and couple the
shaft to it. Mark where the shaft enters the coupler.
- Make sure the coupler won't be rubbing on mount while it spins.
4. Make sure the hammer has about 5/8" clearance from the mount.
- If not, you can pull it out of the coupler a little, but make sure the bolt won't be too close to the edge.
- Otherwise, you can grind away the tacks on the hammer and tack it properly.

### 3. Drill Hole for bolt in coupler

1. Remove the motor and shaft from the mount
2. Put the coupler back onto the shaft.

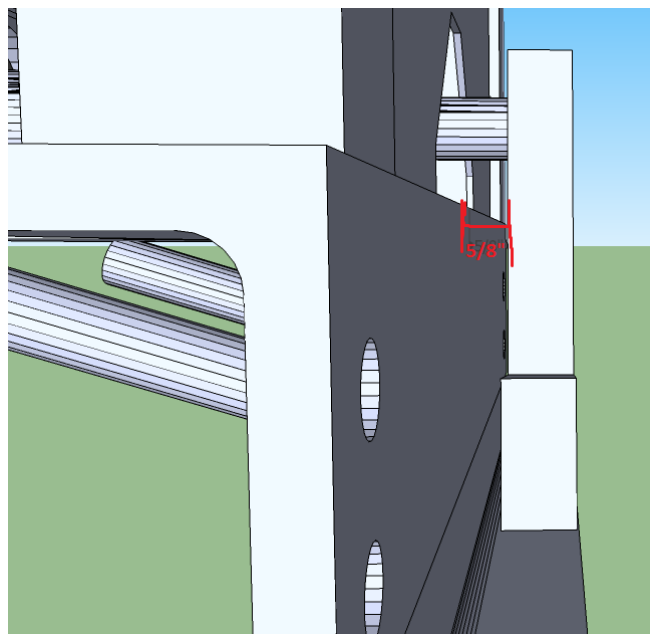
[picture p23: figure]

3. Drill the 1/4" hole thru the coupler and rod, using the mark you made to make sure the rod is inside the coupler the proper amount.
- The hole should be 3/8" away from the edge of the coupler.
- Drill thru both at the same time. You will need some sort of vice to hold it down while you drill.
4. Double check that your bolt will fit thru. If not, either re-drill it.

CEB Shaker – Hydraulics Assembly (5)

# CEB Shaker – Hydraulics Assembly

Tools Needed:
- Vise
- Various Wrenches

Things to know about working with hydraulics:
- Thread tape is necessary between each connection unless otherwise stated.
- Always wrap thread tape clockwise when facing the threaded portion.
- Always keep the end caps on hoses and fittings until you need to take them off. They need to stay protected inside.
1. Attach all of the fittings and the 2 hoses to the
2. Tighten the tee assembly into the correct port (see
3. Install the swivel and tighten the small hose to it.
4. Put the other 36" hose into the remaining port on

Materials Required:
- Thread tape
- Shaker motor Buy (https://www.surpluscenter.com/item.asp?item=9-7077-50&catname=hydraulic)
- 1/2" NPT Needle Valve (1) Buy (http://www.surpluscenter.com/item.asp?item=9-7960-8&catname=hydraulic)
- 1/4"x12" NPTM Hydraulic hose (1)Buy (https://www.surpluscenter.com/item.asp?item=916-1412&catname=hydraulic)
- 1/2"x36" NPTM Hydraulic hoses (2)
- SAE 4M to 1/4" NPTF Swivel (1)Buy (https://www.surpluscenter.com/item.asp?item=9-6900-4-4-S&catname=hydraulic)
- 1/2" NPT Hex Nipple (2) Buy (https://www.surpluscenter.com/item.asp?item=9-5404-8-8&catname=hydraulic)
- 1/2" NPTF Tee (1) Buy (https://www.surpluscenter.com/item.asp?item=9-5605-8-8-8&catname=hydraulic)
- 1/2" NPTM to 1/4" NPTF bushing Buy (https://www.surpluscenter.com/item.asp?item=9-5406-8-4&catname=hydraulic)

CEB Hopper and Grate Supports (6)

# CEB Hopper and Grate Supports

- Hopper Support Model (http://sketchup.google.com/3dwarehouse/details?mid=e4c762d16d8f60401211da1f85706ccd)
- Grate Support Model (http://sketchup.google.com/3dwarehouse/details?mid=692395798fa885f71211da1f85706ccd)

Tools Needed:
- Angle Grinder
- Welder
- Hole Puncher
- Torch

## Hopper Supports

1. Torch away the necessary areas. See diagrams.
- The holes for the hopper mounting need to be 28" away from the bottom side. Mark 28" on the opposite tubing walls and torch 1/2" holes. Insure a 1/2" bolt goes all the way thru.
- Torch the cutaway at the top and the slot.
2. Grind away any slag.

Materials Required:
- ¼”x2”x2” Tubing- 48” (2) Hopper supports
- ½”x4”x4” Angle- 38” (2) Grate Supports
- Shaker mount
- ¾”x1.5” Bolts (2)
- ¾” Nuts (2)

CEB Hopper and Grate Supports (6)

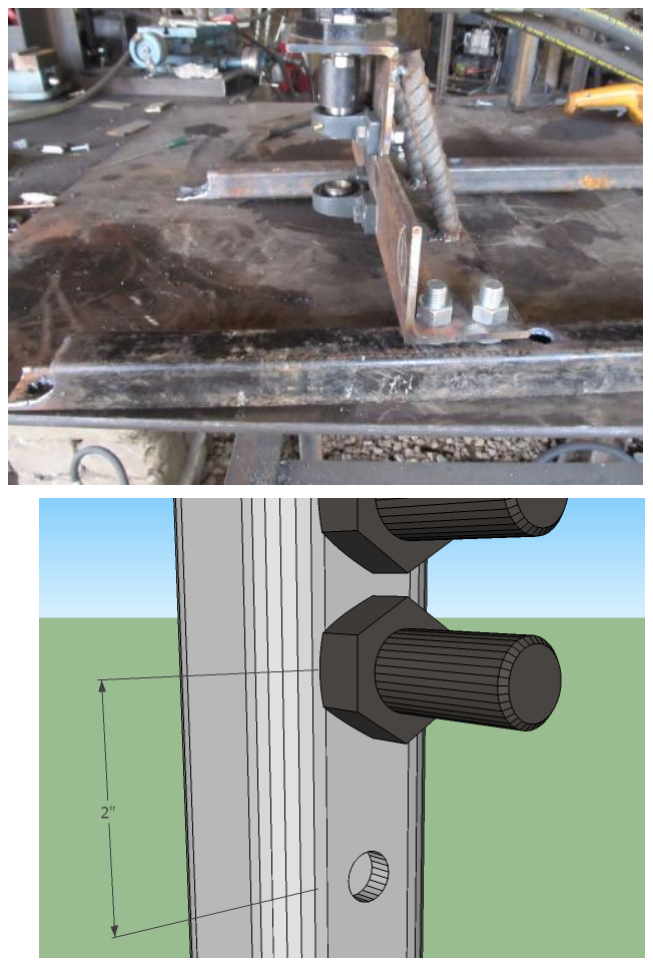
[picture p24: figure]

### 3. Weld the shaker mount bolts to it

- Lay one support on the table, with the grate mount slot touching the table.
- Get the Shaker Mount and tighten
3/4" bolts with nuts to the Soil
Shaker as shown.
- Prop this up on the hopper support, so the first bolt is about 2" above
the 28" hole and both bolts are
touching the support.
- Mark on the mount which side of the shaker you are welding the bolts for.
- Tack the bolts in place, remove the nuts and dismount the shaker.
- Protect the threads, and finish welding the bolts to the support.
- You are only doing this on one of the supports. The other side, you will do in place, so the spacing is correct.

## Grate Supports

### 1. Torch away a 4" section on the top of each

grate to make it like the model shown.
- Remember that the two are mirrored.
2. Cut away the corner so the hopper won’t hit it, about a 1" 45 degree triangle.

### 3. Torch a slot for a 3/4" bolt at the top of the

mount, as shown.
4. Grind away all the slag.

# CEB Hopper Sheet metal

CEB Hopper Sheet Metal (7)

Sketchup Model (http://sketchup.google.com/3dwarehouse/details?mid=4b2a714d7ad6bbe01211da1f85706ccd)

Tools Needed:
- Angle Grinder
- Welder
- Hole Puncher
- Torch
- Wrenches or Sockets

### 1. Prepare the Hinge plates

- Punch holes in 4 of the hinge plates as shown
- Weld one plate with holes, one without holes, and 3 hinges together as shown.
- Make sure the side of the hinge that sticks out most is on the top; this way it won't interfere with the hopper metal below when installing the hopper. (See photo)
- Make 3 more of these. (4 Total)

Materials Needed:
- Torched Hopper Sheet Metal (see cut list)
- 1/8”x3” Flat- 24” (12) Hinge plates
- Hinges (12)
- 1/2"x1" Bolts (12)
- 1/2" Nuts (12)
- 1/2" Washers (12)

CEB Hopper Sheet Metal (7)

### 2. Hopper Sheet Metal

- Torch the holes shown in the front piece.
- Punch all of the holes shown in the side pieces and dirt deflector.

### 3. Weld the bolts

- Place 1/2" bolts thru the side pieces and weld them.
- Make sure you are making them mirror images of each other.

### 4. Assemble

- Bolt the hinge plate assemblies to the side pieces using a washer, lock washer, and nut on each bolt

# CEB Hopper Mounting Plate

CEB Hopper Mounting Plate (8)

Sketchup model (http://sketchup.google.com/3dwarehouse/details?mid=1951330c482561411211da1f85706ccd)

Tools Needed:
- Angle Grinder
- Welder
- Hole Puncher
1. Punch the holes in the 15" pieces. They are both the same.
2. Weld the pieces together, insuring everything is
square.
- There should be a
6" space between
the 15" pieces.
- Skip around so the
plate doesn’t
warp.
- Weld both sides on
all seams
3. Grind away the welds on one side of the plate.

Materials Needed:
- ½”x3” Flat- 15” (2)
- ½”x3” Flat-11.25” (2)

# CEB Grate

CEB Grate (9)

Sketchup Model (http://sketchup.google.com/3dwarehouse/details?mid=90f0d51891aea14a1211da1f85706ccd)

Tools Needed:
- Angle Grinder
- Welder
- Torch

### 1. Prepare the frame

1. Torch all holes and slots in the 72” 2x2’s as shown. Note that the slots are ½” tall.
- Make sure you can fit the proper size bolt through each hole.
2. Grind away any slag
3. Weld the nuts to the proper 2x2.
- Protect the threads while you weld.

Materials Needed:
- ½”x2”x2” Angle- 72” (2)
- ½”x2”x2” Angle- 35.5” (2)
- ½”x2 Flat- 71.5” (1) Cross Piece
- ½” Rebar- 34” (33)
- ¾” Steel Nuts (2)

CEB Grate (9)

2. Weld the angle together to make the frame. The short pieces are sandwiched between the long pieces. See the diagram.
3. Weld all of the rebar inside of the frame.
- It would help to find some 1.5" spacers laying around the shop so you can place them between

the rebars quickly and be sure they are square. Nuts and hydraulic fittings might be the right size.

•
4. Weld the cross support (the 1/4 x 2 flatbar) in centered and perpendicular to the plane of the frame

CEB Soil Loading Drawer (10)

# CEB Soil Loading Drawer

Sketchup model (http://sketchup.google.com/3dwarehouse/details?mid=1951330c482561411211da1f85706ccd)

Tools Needed:
- Angle Grinder
- Welder
- Squares

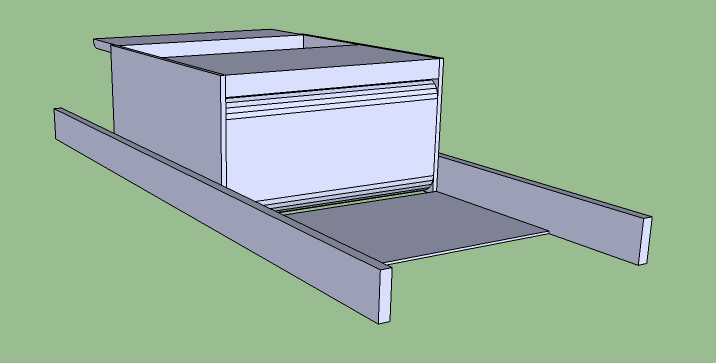
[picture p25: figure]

Step 1 — Weld Press Plate to Spacer
1. Lay the spacer tube on top of the press plate, align the sides and make the back edge flush.
- Insure all edges are tight and squared; this piece is critical, it must be a uniform height throughout the entire item. Grind off any imperfections.
2. Tack weld the two together in many places (at least 3 on each seam).
- Double check everything for squareness!!
3. Weld the two together on all edges where they touch
- It is a good idea to weld in 1” or 2” increments, skipping around to different places to prevent warpage. You will need to weld multiple layers where the tubing is rounded.
StockSize | Size (Inches) | Length (Inches) | QTY. | Primary Part Name
Angle | .5x4x7 | 12 | 1 | Back
Flat | .1875x2.5 | 36 | 2 | Outer Rails
Flat | .25x7 | 13.5 | 2 | Sides
Flat | .25x8 | 12.5 | 1 | Roof
Flat | .5x2 | 36 | 2 | Inner Rails
Flat | .5x3 | 3 | 1 | Tongue
Flat | .5x6 | 12 | 1 | Vertical Supports
Flat | 1x7 | 12 | 1 | Press Plate
Tubing | .5x6x6 | 12 | 1 | Spacer

Materials Needed:

CEB Soil Loading Drawer (10)

Step 2 — Weld the vertical support
1. Place the vertical support and tack it in multiple places
2. Weld the vertical support to the press plate and spacer tube assembly.
3. Grind down the welds on the open end of the tube so they are flush with the rest of the tube.
Step 3 — Tack Sides
1. Lay the spacer/press plate assembly down so the press plate is touching the table.
2. Align side pieces with spacer and press plate assembly.
3. Insure the two are square vertically and horizontally with the spacer, that they are parallel, and that everything is touching the table.
- It helps to use angle iron tacked to your table and the sides, so it insures they are vertically square. This also makes it a bit easier to align everything else. Video Help (http://www.youtube.com/watch?v=HnFXzrwzsjg&list=UUjvBN1r7UXXqmIbx_u7bIAw&index=339&feature=plpp_video)
- Also, it may help to use paper shims (see
between the sides and the tube to properly space them. Video Help (http://www.youtube.com/watch?v=bahhYtxy4Zg&list=UUjvBN1r7UXXqmIbx_u7bIAw&index=203&feature=plpp_video)
4. Tack the sides to the tube on all sides in multiple places except where it is touching the table. Add a few 1" seams to prohibit them from moving.
- Do a few light tacks first, and double check it's still square. If not, grind off the tacks and start over.

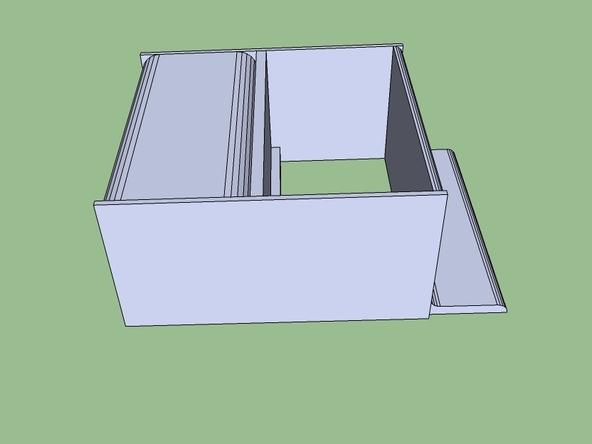
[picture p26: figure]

Step 4 — Tack the back
1. Tack the back piece in a few spots, with a 1" seam on each side.

CEB Soil Loading Drawer (10)

Step 5 — Tack Roof, Inner Rails
1. Grind off the welds for the back and side pieces so that the entire drawer is flush.
2. Flip the drawer over and tack the sides from the top.
3. Place the roof and inner rails in their respective places. See Diagram.
4. Insure inner rails are perfectly parallel (varying no more than a 16th of an inch) and square throughout the entire length.
5. Tack them in multiple places except where they are touching the table.
Step 6 — Tack Outer Rails
- Insure they are perfectly parallel; otherwise they will leave the roller guides. Insure they vary no more than 1/16" over the entire length.
- Hint: Use paper shims for this.
Step 7 — Weld Entire Drawer
- All the seams should be completely welded except the difficult to reach places between the inner and outer rails, those can be welded about 50%.
- Weld short lengths at a time and jump around a lot to minimize warping.
- You may want to grind off the welds in between passes around the drawer to allow it to cool.
Step 8 — Grind the entire drawer flush
- There cannot be any outstanding bumps or welds anywhere;
the drawer will be sliding in and out of a tight spot and bumps
will catch on the frame crossmembers.
- Make sure there's no welding spatter where the rollers will be rolling. Grind any off with a small grinder.

CEB Soil Loading Drawer (10)

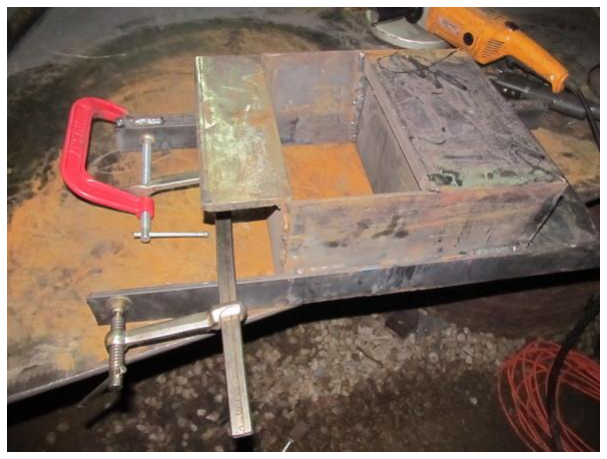
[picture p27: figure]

Step 9 — Check the Rails
- The rails likely got warped outwards on the side with the back while you were welding.
- If they are not still parallel, you will need to pinch them inwards so that they are. You can do so using two C-Clamps as shown.
Step 10 — Weld Tongue In place
- Prepare as shown in the diagram
- Weld it to the back of the drawer, insuring it is square and centered.

CEB Roller Guides (11)

# CEB Roller Guides

Sketchup Model (http://sketchup.google.com/3dwarehouse/details?mid=fbd68b54bc8624011211da1f85706ccd)

Tools Needed:
- Angle Grinder
- Welder
- Hole Puncher
- Wrench
1. Punch the holes in the main plates and the spacer plates.
2. Weld the 1/2" bolts in the center hole, from the bolt head side.
3. Grind off the top of the 12mm bolts so that the head is 1/4” thick or less.
- This is so that the bolts will not be touching the drawer as it slides in and out.
4. Assemble the bearings to the plate as shown, with lock washers on each side of the main plate.

Materials Needed:
- ½”x3” Flat- 16” (2)
- V-Groove Bearings (4)
- 1/2"x 2.5" Bolts (2)
- M12x55mm Bolts (4)
- M12 Nuts (4)
- Washer, Lock 12mm (8)

CEB Wide Cylinder Supports (12)

# CEB Wide Cylinder Supports

Sketchup Model (http://sketchup.google.com/3dwarehouse/details?mid=31ebd3ea006a79211211da1f85706ccd)

Tools Needed:

- Angle Grinder
- Welder
- Square

You need to make two of these. They can be exactly the same.

1. Torch the hole in the 2x2 angle as shown.
2. Weld the angle centered on the U-channel. (see image above)
3. Weld a 3/4" bolt over the hole.
- Protect the threads
4. Put a galvanized nut on a 3/4"x2" bolt and thread through the welded nut on each side.

Materials Needed:
- 6” Heavy U-channel - 21” (2)
- ¼”x2”x2”Angle - 6” (2)
- ¾” Steel Nuts (2)
- ¾” Galvanized nuts (2)
- ¾”x2” Bolts (2)

CEB Main Frame Small Components (13)

# CEB Main Frame Small Components

Sketchup Model (http://sketchup.google.com/3dwarehouse/details?mid=c94fa5ac3a7bcccd1211da1f85706ccd)

Tools Needed:
- Welder

## Sensor Holders

- One is for the main frame, and one goes in the primary arms.
1. Weld the rebar to the threaded rod at a right angle.
- Protect the threads on the threaded rod by welding. (A small pipe works well)
2. Thread a nut onto it.

Materials Needed:
- ¾” Steel Nuts (2)
- ¾” Galvanized Nuts (3)
StockSize | Size
| (Inches) | Length
| | (Inches) | QTY. | Primary Part Name
C-Channel | 3 | 1.5 | 2 | Thin Cylinder support
Flat | .25x1 | 14 | 1 | Magnet Holder
Pipe | .75ID 1OD | 1 | 2 | Thin Cylinder support
Rebar | 0.375 | 3 | 1 | Sensor Holder
Rebar | 0.375 | 6 | 1 | Sensor Holder
Threaded Rod | 0.75 | 1.25 | 1 | Magnet Holder
Threaded Rod | 0.75 | 3.5 | 1 | Sensor Holder
Threaded Rod | 0.75 | 3.5 | 1 | Sensor Holder
Threaded Rod | 0.75 | 6.25 | 2 | Thin Cylinder support

## Thin Cylinder Supports

CEB Main Frame Small Components (13)

- Weld the 1" pipe to the 3" U-channel, in the center. 4-8 good tacks is sufficient.
- Make (2) 6" long 3/4" bolts, by using a nut and 6.25" of threaded rod. See Making Bolts.

## Magnet Holder

1. Weld the flatbar to the 1.25" piece of threaded rod.
- Protect the threads.
- Make sure they are perfectly paralell!
2. Thread a nut onto the threaded rod.

CEB Main Frame U-Channel Prep (14)

# CEB Main Frame U-Channel Prep

Sketchup Model (http://sketchup.google.com/3dwarehouse/details?mid=3fbeaaff733e760f1211da1f85706ccd)

Tools Needed:
- Angle Grinder
- Welder
- Hole Puncher
- Torch

## Prepare the Horizontal Members

- Mark the holes in the horizontal members as shown in the diagram. Center punch them.
- DON'T PUNCH THEM! They will be mag-drilled in a later guide.

## Prepare the Drawer Members

1. Mark and center punch the 4 holes on the face of the U-channel.
- DON'T PUNCH THEM! They
will be mag-drilled later.

Materials Needed:
- 6” Heavy U-Channel- 21” (2) Horizontal Members
- 6” Heavy U-Channel- 53” (2) Vertical Members
- 6” Heavy U-Channel- 29” (2) Drawer Members
- ¾” Steel Nuts (10)
- ¾” Galvanized Nuts (4)
- ¾” Threaded Rod- 3.75” (4) Drawer Adjustor bolts

CEB Main Frame U-Channel Prep (14)

2. Torch holes for 3/4" drawer adjustment bolts as shown in the diagram.
3. Grind away the slag.
4. Weld 3/4" nuts to the outside of the U channel where the holes are torched.
- Weld it with a bolt coming thru the other side so it protects the threads and so you know the nut won't get off center.
5. Grind away any spatter between the bolts.
6. Make (4) 3/4" x 3.5" bolts using 3.75" threaded rod and
steel nuts. See Making Bolts. (http://opensourceecology.org/wiki/Making_Bolts)
7. Thread the bolts through the nuts and thread another nut on top as shown.

## Prepare the Vertical Members

1. Punch the holes as shown.
2. Torch the roller slots as shown.
3. Grind away the slag.
4. Weld the the thin cylinder support nuts, taking care to protect the threads.

CEB Prepare the Press Feet (15)

# CEB Prepare the Press Feet

Sketchup Model (http://sketchup.google.com/3dwarehouse/details?mid=c191f7e6d624554a1211da1f85706ccd)

Tools Needed:
- Angle Grinder
- Welder
- Hole Puncher
- Drill Press or Mag Drill with 13/16” Bit

## Lower Press Foot

1. Mark and drill or punch the holes (13/16") in the lower press foot.
2. Place this centered on the upper press plate and transfer punch the hole locations.
3. Mag-drill these holes.

Materials Needed:
- 1”x4” Flat- 10” (1) Lower Press Foot
- 1”x6” Flat- 12” (1) Upper Press Foot
- ¾” Threaded Rod- 2.5” (2) Upper Press Foot

CEB Prepare the Press Feet (15)

4. Torch out the hole in the center of the lower press plate.
5. Grind it smooth.

## Upper Press Foot

1. Plug weld the threaded rod into the upper press plate, so that the threaded rod is about 1/4" deep in the plate.
2. Fill the hole with weld, then grind it flush.
- The upper press foot NEEDS to be 12" exactly across at the top of it (the side without the bolts sticking up) or there will be "fuzzy edges" on your bricks. See the video (http://www.youtube.com/watch?feature=player_embedded&v=mh7XqmTbA0g) for more info.

CEB Prepare the Main Cylinder (16)

# CEB Prepare the Main Cylinder

Sketchup Model (http://sketchup.google.com/3dwarehouse/details?mid=47b29a6164503891211da1f85706ccd)

Tools Needed:
- 3/8" Allen Wrench (http://makeprojects.com/Item/3_8%22_Allen_Wrench) | • The Press Feet
- Bucket and Water for cooling cylinder (http://makeprojects.com/Item/Bucket_and_Water_for_cooling_cylinder) | • The Main Cylinder
- Hydraulic Pump (http://makeprojects.com/Item/Hydraulic_Pump) | • 1/4" to 1/2" Bushing (2)
- Large Square (http://makeprojects.com/Item/Large_Square) | • 1/2" NPTM to 1/2" NPTF Elbow
- Speed Square (http://makeprojects.com/Item/Speed_Square) | (2)
- Thread Tape (http://makeprojects.com/Item/Thread_Tape) | • 1/2" Hex Nipple (2)
- Vise (http://makeprojects.com/Item/Vise) | • 1/2" Quick Coupler Set (1)
- Welder (http://makeprojects.com/Item/Welder) | • 3/4" Galvanized Nuts (2)
- Various wrenches (http://makeprojects.com/Item/various_wrenches) | • 3/4" Steel Nuts (1)

## Step 1-- Prepare the Hydraulic Couplers

- Thread tape is necessary between each
connection. Always wrap thread tape clockwise
when facing the threaded portion.
- You will need to make 2 of these, one with male quick couplers and one with a female.
1. Put the hex nipple in the vise and tighten the quick coupler onto it. Put the elbow in the vise, male side up, and tighten the bushing onto it.
2. Rotate the elbow in the vise and tighten the quick coupler/ nipple onto it.

Materials Needed:

CEB Prepare the Main Cylinder (16)

## Step 2 — Install the Couplers

1. Remove the plugs on the cylinder.
- The Prince brand cylinder uses a really large allen wrench for their plugs. If you can't find one, you can make one like we did.
- Make sure the ports are facing up as there might be
fluid in the cylinder and you don't want it to leak.
2. Tighten the coupler assembly into the holes, so that when the cylinder is lying on its side, neither one will hit the table.

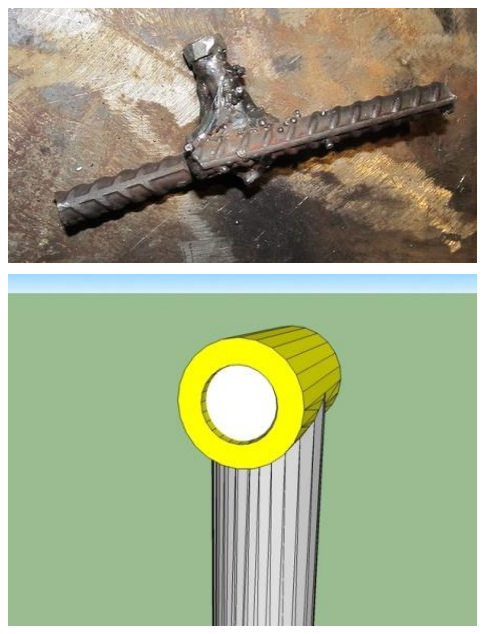
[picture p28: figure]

## Step 3 – Weld the Filler Rod

1. Expand the cylinder so the shaft is fully extended, using a hydraulic pump.
2. Weld a 3.5" piece of 1.5" DOM roundstock inside of the tubing at the end of the shaft
- Take care that the top of the shaft doesn't get hot; there is a rubber seal between that and the cylinder that will melt and cause leaking if you're not careful. If it starts getting warm, dunk the shaft in water to cool it down.

## Step 4 — Tack the Lower Press Foot to the Cylinder

1. Stand the cylinder up vertically and prop it up using some sort stand so it is as close to square vertically as possible. Another option is to support it using some sort of rope.
2. Place the tubing at the end of the shaft inside of the hole in the lower press foot.
3. Insure the cylinder is square to the plate in all directions. See video. (http://www.youtube.com/watch?feature=player_embedded&v=_pICqVpcZ8E)
- Since there is a lip on the cylinder, its hard to tell if it's square unless you use two squares, one on the lip and against the other one which rests on the table.
4. Tack the lower press foot from all accessible dimensions.
5. Insure the cylinder is still square with it, if not, remove the tacks and fix it.

## Step 5 – Weld the top

1. Weld the two together on the top. There will need to be at least 2 layers of weld.
- Warning: Dunk this frequently, even if the shaft is not getting hot! The plate will warp upwards and cause you lots of woe if you do not.
2. Weld the press foot support pieces as close as you can to the tubing and the press plate.

CEB Prepare the Main Cylinder (16)

## Step 6 – Weld the Bottom

1. Lower the cylinder and flip it upside down.
2. Fill in the bottom side of it with welds.
- This will require many layers of welds and many dunks to cool it.
3. Grind it flush with the rest of the plate.
- A few spots where the welds are below the surface is OK, but the majority of the surface should be level.

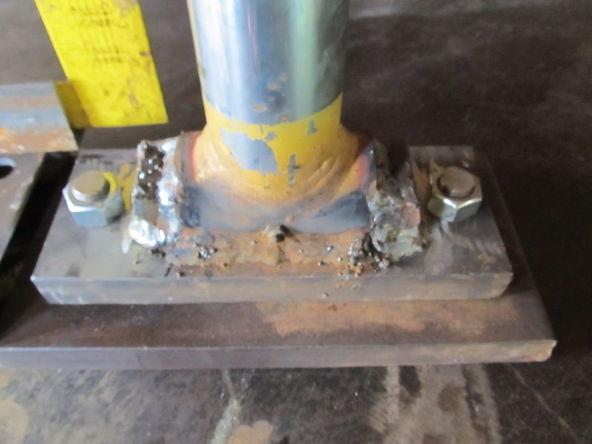
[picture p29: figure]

## Step 7 — Install the Upper Press Plate

1. Put the upper press foot into the lower one and tighten nuts onto the threaded rod.
2. Stand the cylinder up again and insure the press plate is still square with the cylinder. See video. (http://www.youtube.com/watch?v=_pICqVpcZ8E&list=UUjvBN1r7UXXqmIbx_u7bIAw&index=326&feature=plpp_video)
- If it’s not, you'll need to add shims between the two press plates until they are square with the cylinder.

## Step 8 — Weld the magnet holder nut

Weld the nut in the corner of the lower press plate, as shown.
- This should be on the opposite side of the ports of the cylinder, flush with the press foot, and as near to the corner as you can get it. It can even hang off a bit.
- Make sure you protect the threads.

CEB Frame U-Channel Assembly (17)

# CEB Frame U-Channel Assembly

Sketchup Model (http://sketchup.google.com/3dwarehouse/details?mid=8814c7c276992d9c1211da1f85706ccd)

Tools Needed:

- Large Square (http://makeprojects.com/Item/Large_Square) | • The Prepared U-Channel
- Mag-Drill (http://makeprojects.com/Item/Mag-Drill) | • Wide Cylinder Supports
- Vise Grips (http://makeprojects.com/Item/Vise_Grips) | • ¼”x2”x2” Angle- 6” (2) Dirt Blockers
- Welder (http://makeprojects.com/Item/Welder) | • 3/8”x3” Flat- 24” (2) Drawer Member Reinforcements
- c clamps (http://makeprojects.com/Item/c_clamps) | • 6” Heavy U-Channel- 13” (2) Spacers

## Step 1 — Clamp the Vertical Pieces

1. Gather materials for the “Jig”; this means 6”x12” tubing (52”) and any extra heavy U Channel. If you don't have any laying around, you can use one drawer member, and one spacer on each side.
2. Clamp the vertical pieces to the "Jig" on each end, with extra U channel in between the tubing and the vertical pieces.
- Make sure they are both orientated properly, that is that both roller slots are at the same end of the jig.
- Insure the two verticals are flush at the top end.

Materials Needed:

- 3/4"x2" Bolts (16)
- 3/4" Galvanized Nuts (16)
- 3/4" Washers (16)
- 6”x12” Tubing – 52” Optional Jig

CEB Frame U-Channel Assembly (17)

Step 2 — Clamp the Horizontals.
1. Clamp one horizontal member at each end of the jig.
- Make sure they are flush with the ends of the verticals and centered on them.
- Insure they are square with the jig by using a large square.
2. Clamp using 1 or 2 vise grips on either side.
- If you didn't need to use the drawer members for the jig, you can drill those and the wide cylinder support holes now too so you
won't have to handle the material
twice. See below (http://makeprojects.com/Project/CEB-Main-Frame-Assemble-U-Channel/1740/1#s8956) for how to do it.
- It really helps to label each member, so that if you end up unbolting the piece later, you'll know exactly where it goes and in what orientation. Mark which side will be the top of the machine (could be either end at this time), and which
member goes where.

## Step 3 — Mag-Drill the holes and bolt to frame

1. Use a Mag-Drill to drill the 3/4" holes each place where the horizontal members overlap the vertical members.
2. Bolt the horizontal members tightly to the vertical members.
3. Flip the jig over so you have access to drill the other holes. See video (http://www.youtube.com/watch?v=cwuQaTd2QZw) for help.
4. Clamp the other 2 horizontal members in place.
5. Align the other horizontal members with the ones below the jig, so that they are both at the same location relative to the vertical members.
- This is crucial so that the machine will stand up straight and there won't be any gap between the drawer and the top horizontal members.
6. Insure once more that the horizontal members are square with the vertical members.
7. Mag Drill them.

CEB Frame U-Channel Assembly (17)

8. Remove the clamps and the jig from the frame.
9. Bolt the horizontals tightly to the frame.
10. Double check to make sure everything is still square.
- If not, loosen the bolts and square it up on what you labeled top first and tighten those bolts. Then square out the other side and torch out any spots prohibiting the bolts from going thru.
- Bolt it back when you're done.

## Step 6 — Mag-Drill the holes for the wide cylinder supports and drawer members

1. Clamp the drawer member centered, 7" from the upper cross member.
- The drawer slots should be on this side, not opposite.
- Make sure the adjustment nuts are facing where the drawer was, look at the picture.
2. Clamp the wide cylinder support adjacent to it.
3. Make sure you label each component for re-assembly later.
4. Mag-Drill 1" holes at these centers.
5. Don't bolt these yet, you'll do that later.

## Step 7 — Re-inforce the drawer members

- Place the 1/2"x3"x24" flats on the drawer members centered as shown.
- Weld them in place, using about a 50% weld.

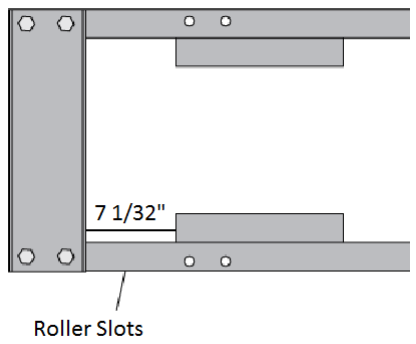
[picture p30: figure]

## Step 8 — Tack the Spacers

- Note: You not welding them because when you stretch the frame, it may "move" their location.
1. With the frame laid down, and one of the drawer members under it to support the spacers, place the spacers on each side.
- The end of them is to be 7 1/32" away from the upper cross member. Look at the diagram.
2. Insure they are parallel and flush with the U-channel and C-clamp in two places for each.
3. Tack them on this side in 3 spots.
- You may need to grind this off later, so make sure the tacks aren't longer than 1/4" or so.
4. Flip over the frame and tack the other side.

CEB Frame U-Channel Assembly (17)

## Step 9 — Weld the Dirt Blockers

1. Put the dirt blockers in place, between the vertical members, so the bottom side of them is about 1/8" above the bottom of the upper crossmembers.
2. Weld the portion inside of the vertical members, taking care to not weld them to the crossmembers.

CEB Fit the Main Cylinder (18)

# CEB Fit the Main Cylinder

Sketchup Model (http://sketchup.google.com/3dwarehouse/details?mid=1289cc9979d24e3d1211da1f85706ccd)

You need to fit the cylinder into the frame so that when it is fully extended, the press foot is in the correct spot to eject the brick. You will need to torch holes in the horizontals for the pin which goes thru the cylinder, and weld DOM tubing to hold the pin. We recommend you watch the instructional video. (http://www.youtube.com/watch?feature=player_embedded&v=F9QAa7oHbiE)

Tools Needed:
- Angle Grinder
- Welder
- 1/8” thick washer
- MIG welder (http://makeprojects.com/Item/MIG_welder) | • Pin Receptors: 1.5" inner
- Speed Square (http://makeprojects.com/Item/Speed_Square)
- Spray paint (http://makeprojects.com/Item/Spray_paint)
- Torch (http://makeprojects.com/Item/torch)

## Step 1 — Position the Cylinder

1. Lay the frame down, with all of the crossmembers and drawer members in place except the upper crossmember and drawer member which are facing up.
2. Place the assembled cylinder lying down so that the press feet are between the spacers. You need to insure that the vertical height is correct, and that the cylinder is centered.
- Insure the magnet holder nut (welded to the press feet) is on the same side as the sensor holder hole (hole in one vertical).
- The top of the upper press foot should be 6 3/4" for monster away from the bottom of the upper crossmembers.

Materials Needed:
- Prepared main cylinder (http://makeprojects.com/Item/Prepared_main_cylinder)
- Pin-1 1/2" DOM Roundstock, 11" (http://makeprojects.com/Item/Pin-1_1_2%22_DOM_Roundstock_8.5%22)

diameter, 2" outer diameter DOM tubing: 1.5" (http://makeprojects.com/Item/Pin_Receptors_1.5%22_inner_diameter_2%22_outer_diameter_DOM_tubing_1.5%22) (2)

CEB Fit the Main Cylinder (18)

## Step 2 — Squaring the cylinder

- Add a 1/8" spacer (big washers work great) under the cylinder, where it contacts the lower crossmember. This insures the cylinder is centered vertically. Where to put it is circled in the first image.
- Make sure the cylinder is centered, using a speed square pressed against the side of the cylinder, and a tape measure to the to the vertical members as shown.
- Make sure the tubing for the pin is square with the lower crossmember using a speed square.

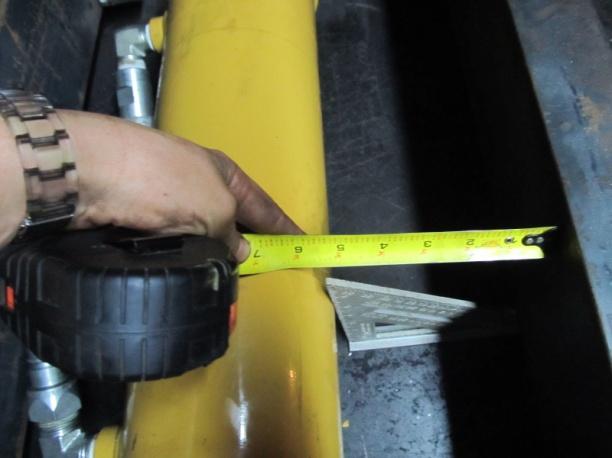
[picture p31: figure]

## Step 3 — Marking hole locations

1. Mark the location for the hole for the pin on the bottom horizontal member using spray paint.
2. Put the top horizontal member on, and put in at least 3 bolts.
3. Spray mark this location as well, from the other side.
4. Remove the horizontal members from the frame.
- This is possible to do without removing the cylinder, just prop it up on something to remove the lower member.
5. Place one of the DOM tubing pieces in the center of each of the sprayed marks and spray paint around this to mark where you will torch.

CEB Fit the Main Cylinder (18)

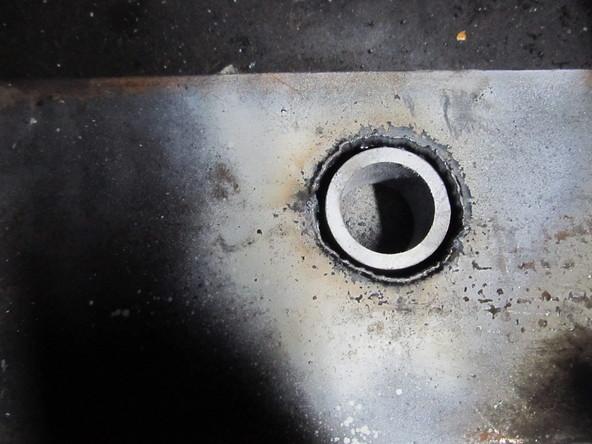
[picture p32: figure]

## Step 4 — Torching

1. Torch out the hole, and grind away the slag.
- Insure the tubing will go thru each hole. If not, retorch it. Grind off the slag.
2. Lay the cylinder back down, with the 1/8" spacer in, and replace the crossmembers, with their bolts. Place the tubing in the torched holes.
3. Insure the pin will go thru the tubing and the cylinder. If not, retorch the holes so that it will.

## Step 5 — Welding

1. With the pin held in, tack the tubing on the top in place.
- Make sure the tubing is pressed up against the cylinder, that is that it’s as far into the hole as possible.
- You’ll want to tack it in many places before welding around it, at least 8 on each side.
2. Tack it as best you can on the bottom by hanging the frame off of the table and overhead welding. Again, insure the tubing is pressed up against the cylinder.
3. Remove cylinder and pin, as well as the two crossmembers.
4. Fully weld the tubing on both sides. Jump around a lot to minimize any warping on the tubing.
- Block the insides of the tubing so no spatter goes inside. Big washers work well for this.

## Step 6 — Re-Assembly

1. Replace the crossmembers and the cylinder.
2. Insure the pin still fits and hammer it thru.
- If the pin doesn't fit, you will need to make it fit.
- Tighten the bolts on only the bottom crossmember. Put the pin thru the crossmembers and the tube.
- Mark where the bolt holes need to be torched away for the bolts to fit through. Torch it and you're done.

CEB Stretching the Frame

# CEB Stretching the Frame

Tools Needed:
- Hydraulic Pump

### See the Video. (http://www.youtube.com/watch?feature=player_embedded&v=ZpZ0OUmGFIA)

## Step 1-- Stretch the frame

1. Attach the cylinder to a hydraulic pump or power cube and contract the cylinder at least 1".
2. Stand up the frame so the press feet are facing down.
3. Insert the Soil loading drawer on top of the horizontal members so that the press plate is facing the press feet.
- If the drawer doesn't fit because of the spacers, you welded them too close. Grind off the tacks and tack them a little higher.
4. Position the drawer so that the press plate
will be fully contacted by the press feet.
5. Bolt the drawer members on finger tight.
6. Use the pump to expand the cylinder as much as possible. The pump will likely stall out.
- If the pump stalls, turn it back on and expand it fully once more.
7. Expand at least 3 times.
8. Contract it, so you can weld the spacers in. Then detach from the pump.

## Step 2 — Observations

1. Remove the drawer members.
2. Look where the spacers are near the drawer.
- The spacers should be very close to the drawer (less than 1/32")
See quality control video (http://www.youtube.com/watch?feature=player_embedded&v=mh7XqmTbA0g) if you wonder why.
- If they are too far, grind off the welds and re-tack them so they are lightly contacting the drawer. Yet again, make sure they are perfectly square with the verticals.

Materials Needed:
- Main Frame
- Wide Cylinder Supports
- Soil Loading Drawer
- ¾”x2” Bolts (8)
- ¾” Nuts (8)

CEB Welding the Spacers

# CEB Welding the Spacers

Tools Needed:
- Angle Grinder
- Welder

## Weld The Spacers

1. Lay the frame on its side.
2. Protect the cylinder and press feet so that when you weld, spatter won't stick. You could use some piece of metal or a nonflammable cloth.
3. On the inside, bottom edge, weld the interior of the spacer inwards as far as you can. This should be an inch or more. Do this in all 4 corners accessible from this side of the frame. See the photo.
4. Weld the top 100%, and grind it flush.
5. Flip over the frame.
6. Weld this side as you did the other side, also welding inside the spacers.

Materials Needed:
- Main Frame

CEB Frame – Installing the Small Components

# CEB Frame- Installing the Small Components

Sketchup Model (http://sketchup.google.com/3dwarehouse/details?mid=578643debbf3ea461211da1f85706ccd)

Tools Needed:
- Wrenches
- Welder

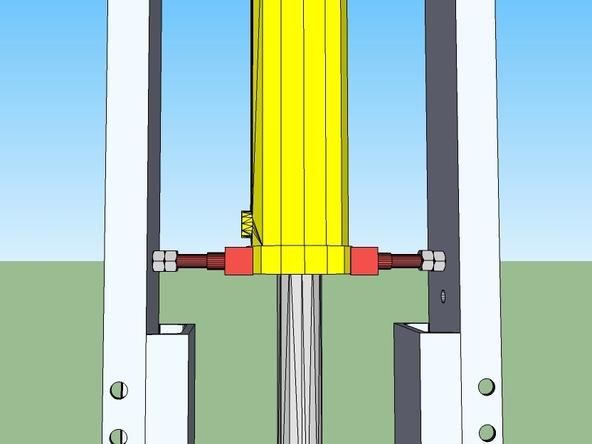
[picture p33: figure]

## Step 1 — Install the thin Cylinder Supports

1. Install the thin cylinder supports by screwing the bolt in with an extra nut on it as shown, and placing the u-channel against the cylinder.
2. Get both of them snug so the cylinder is centered with pressure on each side.
3. Tighten down the nut to lock it.

Materials Needed:
- Main Frame
- Sensor Holder
- Thin Cylinder Supports
- Magnet Holder
- Leg Holders (2)
- ¾” Nuts (3)

CEB Frame – Installing the Small Components

## Step 2 — Install the magnet holder

1. Install the magnet holder onto the press foot.
- The flatbar needs to be parallel with the verticals. If not, bend it so it is.
2. Lock it down with the nut.

## Step 3 — Install the Sensor Holder

- Install the 6" sensor holder so the end of it is overlapping the path of the magnet holder as shown. The other sensor holder will be installed later.

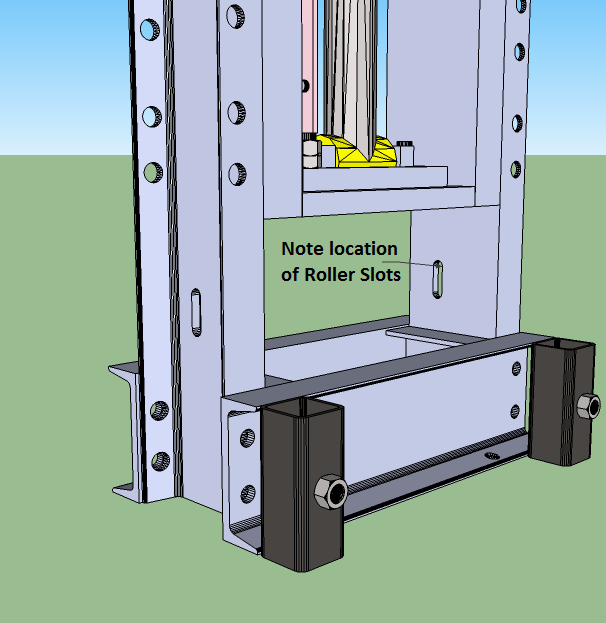
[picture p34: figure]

## Step 4 — Weld the Leg Holders

1. Position them on the upper horizontal members as shown.
- Use the location of the roller guides to insure you attach them to the right side.
- Insure they are square in all directions
2. Weld them to the horizontal members fully.

CEB Fit the Drawer Members

# CEB Fit the Drawer Members

Sketchup Model (http://sketchup.google.com/3dwarehouse/details?mid=9821360314d71e781211da1f85706ccd)

Tools Needed:
- Various Wrenches

## Step 1 — Install the Roller Guides

1. Position frame so it is standing upside down as in picture on right.
2. Install the Roller guides as shown in the illustration. One side should have a 1/2" spacer, and the other should have a 3/8" spacer plate.
3. Tighten the bolts snug, but so that they can still move up and down.

Materials Needed:
- Roller Guides
- Soil Loading Drawer
- Wide Cylinder Supports
- Drawer Members
- 3/4"x2" Bolts (16)
- 3/4" Nuts (16)
- 3/4" Washers (16)
- 1/2" Washer (2)
- 1/2" Lock Washer (2)
- 1/2" Nut (2)

CEB Fit the Drawer Members

## Step 2 – Bolt in Drawer Members

1. Replace the drawer as if you're going to stretch the cylinder again.
- The roller bearings should be on top of the rails on the drawer, and be putting no pressure on the drawer.
2. Loosely bolt on the drawer members.
3. Adjust them horizontally so that the adjustment bolts are centered on the roller guides. See image.
4. Finger tighten the bolts on the drawer members, as they are sitting on top of the drawer.

## Step 3—Adjust Drawer Members

1. Try to slide the drawer in and out. If the drawer gets stuck somewhere, investigate and find where it's hitting. (It almost certainly will).
- You'll probably need to loosen one, or both of the drawer members and move it up a bit.
- This can be done uniformly using cardboard shims. See photo. Place the shim between the drawer and the crossmember. Tighten the bolts again. Remove the shims by "jiggling" the drawer.
- If it's hitting a spacer, grind down the spacer.
- If the drawer itself is prohibitive in some spots, it wasn't grinded evenly. Grind down the high spots.

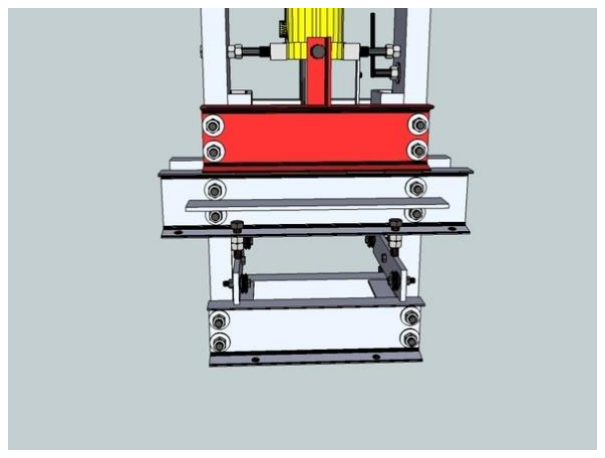
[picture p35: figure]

## Step 4- Tighten all Bolts

1. Once the drawer is properly adjusted, tighten these bolts all the way.
- Make sure the drawer adjustment nuts are still centered on the roller guides.
2. Tightly bolt the wide cylinder supports to the frame, leaving no gap between them and the drawer members.
3. Tighten the bolts at the top of the wide cylinder supports so they are touching the cylinder on each side. Tighten the lock nut.
4. Go back through the entire frame and make sure every bolt is tight.

CEB Secondary Cylinder Hydraulics Prep

# CEB Secondary Cylinder Hydraulics Prep

Tools Needed:
- Various wrenches
- Vise

onto one end of each.
2. Install Assembly #1 into the rod end of the cylinder (image above). Insure the quick coupler will be facing towards the ground when the cylinder is installed.
- When you remove the plug on the cylinder, fluid may spill out, so keep some rags or a jar handy.

You will install the remaining components later upon installing the secondary cylinder.

Materials Needed:
- Thread tape
- 3/8" NPT Hex nipple (2) Buy (http://www.surpluscenter.com/item.asp?item=9-7184&catname=hydraulic)
- 1/2" NPT to 3/8" NPT bushing (2) Buy (http://www.surpluscenter.com/item.asp?item=9-5406-8-6&catname=hydraulic)
- 1/2" NPTF to 1/2" NPTM 90 Elbow
(1) Buy (https://www.surpluscenter.com/item.asp?item=9-5502-8-8&catname=hydraulic)
- 1/2" Flow Control and Relief Valve Buy (https://www.surpluscenter.com/item.asp?item=9-064-50&catname=hydraulic)
- 1/2" Quick Coupler Set (5) Buy (https://www.surpluscenter.com/item.asp?item=928&catname=hydraulic)

CEB Assembly- Structural Components

# CEB Assembly- Structural Components

Tools Needed:
- Angle Grinder
- Welder
- C-Clamps
- Vise Clamps
- Wrenches
- Torch

## Step 1 — Position the main frame

- Set the main frame somewhere on level ground where you have access to a welder and torch and where you have at least an 8' radius of empty space. The CEB takes up a lot of room!
- Set it so the cylinder pin is near the ground.

## Step 2 — Assemble the Secondary Arms

1. Gather the secondary arms, the legs and the feet.
2. Onto the end of each leg, tighten a foot to one of its ends. Get the bolt tight enough so it won't fall off.
3. Insert one leg/foot into each of the outside leg holders on the secondary arms.
4. Adjust the height so that the top of the secondary arms will be very close to the height at the bottom of the primary arms.
5. Tighten the bolts in the leg holders so they are snug, but not too tight.

## Step 3 — Place the Primary Arms

- Clamp them on the drawer members on
the frame so that they are in the proper orientation. See image.
- If the machine is going to tip over, have a friend move the assembled secondary arms to support it so it doesn't tip.

Materials Needed:
- Prepared Structrual Components
- Main Frame
- ¾”x2.5” Bolts (4)
- ¾”x2” Bolts (12)
- ¾” Nuts (17)

CEB Assembly- Structural Components

## Step 4 — Attach the secondary arms to the primary arms

1. Loosely bolt the 2 sets of arms together.
- You may need to loosen the clamps on the primary arms. This is OK.
2. Make sure the arms are all square to each other.
3. Tighten all bolts.
4. Loosen the clamps attaching primary arms to the frame.
5. Square the arms to the frame.

## Step 5 — Attach the primary arms to the frame

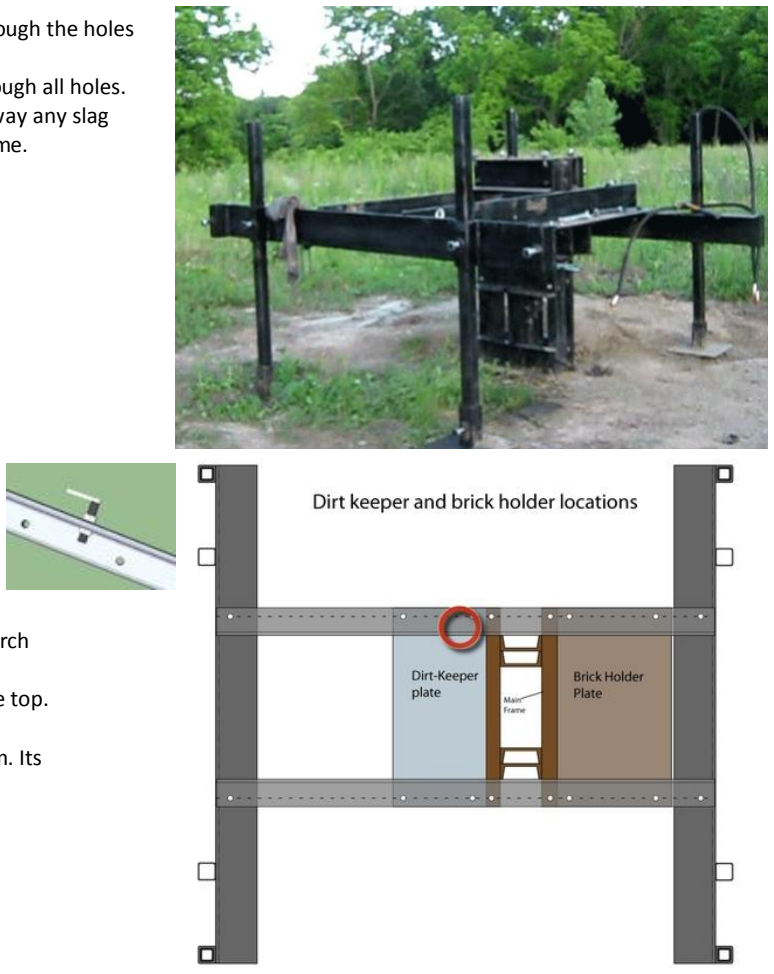
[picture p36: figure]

1. Torch the holes in the frame through the holes in the primary arms.
- Make sure bolts go through all holes.
2. Remove the clamps and grind away any slag
3. Bolt the primary arms to the frame.

## Step 6 — Install Brick Holder plate, Dirt keeper plate, and sensor holder

- The plates go on the bottom side of
the primary arms.
- If not all the bolts go through, torch away whatever is preventing it.
- Bolt them down so the bolt head is on the top. Tighten the nuts snug.
- Install the sensor on the right primary arm. Its location is circled in the diagram.

CEB Assembly- Soil Loading System

# CEB Assembly- Soil Loading System

Tools Needed:

- Angle grinder (http://makeprojects.com/Item/Angle_grinder) | • All Components of Soil Loading
- Spray paint (http://makeprojects.com/Item/Spray_paint) | System
- Vise clamps (http://makeprojects.com/Item/Vise_clamps) | • Assembled Main frame
- Welder (http://makeprojects.com/Item/Welder) | • ¾” Galvanized Nuts (10)
- C- clamps (http://makeprojects.com/Item/c_clamps) | | • 1/2" lock nuts (http://makeprojects.com/Item/1_2%22_lock_nuts) (2)
- Torch (http://makeprojects.com/Item/torch) | | • 1/2" nuts (http://makeprojects.com/Item/1_2%22_nuts) (2)
- Various wrenches (http://makeprojects.com/Item/various_wrenches) | | • 3/4"x1.5" bolts (http://makeprojects.com/Item/3_4%22x1.5%22_bolts) (8)
| | • 3/4"x2.5" bolts (http://makeprojects.com/Item/3_4%22x2.5%22_bolts) (2)

## Step 1 — Torch the holes for the hopper mounting plate

1. Clamp the hopper mounting plate to the top of the main frame, positioned as shown, with the cutaways positioned by the leg holders.
- Clamp it so that the side you grinded down the welds on is touching the main frame.
2. Torch the holes thru to the main frame.
- Check that the fit is good by putting bolts in all the holes.
3. Grind away all the slag.
4. Bolt the mount to the frame.

Materials Needed:

- 1/2"x2.5" bolts (http://makeprojects.com/Item/1_2%22x2.5%22_bolts) (2)
- 1/2"x3" bolt (http://makeprojects.com/Item/1_2%22x3%22_bolt) (2)
- 1/2" washers (http://makeprojects.com/Item/1_2%22_washers) (8)
- 3/4" washers (http://makeprojects.com/Item/3_4%22_washers) (6)
- 1/2"x1" Bolts (http://makeprojects.com/Item/1_2%22x1%22_Bolts) (4)

CEB Assembly- Soil Loading System

## Step 2 — Install hopper supports and prepare

shaker mount.
1. Install the hopper supports into the leg holders.
- Make sure you put the support with bolts on it on the correct side (refer to your shaker motor and look where you marked it.)
- Their bottom side should be flush with the bottom of the leg holders on the frame.
- Make sure they are orientated correctly. See photo.
2. On the side of the shaker motor that you didn't weld bolts for, put a bolt (3/4"x1.5") thru both holes and tighten nuts onto them.

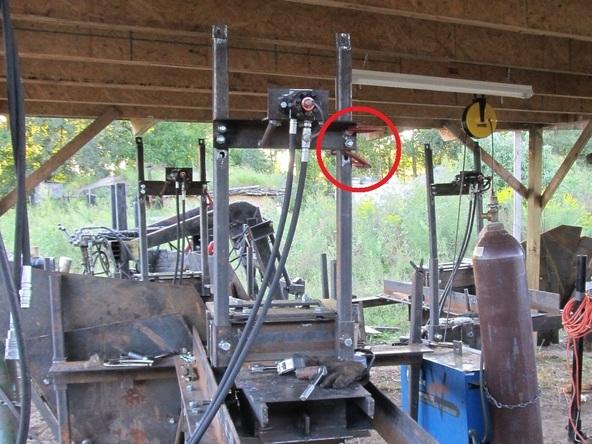
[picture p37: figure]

## Step 3 — Tack shaker bolts to hopper support

1. Place the shaker onto the bolts already welded to the hopper supports.
2. Clamp the other side to the hopper support.
- Use a square to make sure the shaker mount is square with the hopper supports.
3. Tighten nuts onto the side with the welded bolts.
4. Tack the bolts to the hopper support.
- Make sure you tack them to the hopper support, NOT the shaker mount.
- Tack as much as you can from this position.
Step 4 — Weld shaker bolts.
1. Loosen all the nuts and remove the shaker.
2. Protect the threads on the bolts.
3. Weld all the way around the bolt to the hopper supports.
- Don't remount the shaker yet.

CEB Assembly- Soil Loading System

## Step 5 — Clamp the hopper back to supports and torch holes

1. Clamp the hopper back to the hopper supports.
- It should be centered horizontally between them, and touching the supports all the way down to the hopper mounting plate.
2. Torch through the holes circled in the diagram, so you torch through the hopper sheet metal.
- Torch through it on each side, just enough so you have 2 small holes.
3. Un-clamp the sheet metal and torch 1/2" holes for the bolt.
4. Grind off the slag from torching.

## Step 6 — Remount the first plate, and prepare to weld

1. Mount the first plate back to the hopper supports.
- Use a 1/2"x3" bolt and a nut with washers on each side.
2. Lift the side pieces and clamp them to the first plate via the hinge plates.
- Minimize the gap between them as much as you can by pushing them together tightly.

## Step 7 — Weld the hinge plates to the back piece

- Weld it about 50%, as no more is necessary.
- Weld in 3-4 inch sections.

## Step 8 — Clamp and weld the front piece

1. Clamp the final piece in place to the other side of the side pieces.
- Yet again, minimize the gap between the two.
- You may need somebody to get inside of the hopper and push out so you can clamp it well.
2. Weld the last piece like you welded the first one.

CEB Assembly- Soil Loading System

## Step 9 — Place the grate and bolt it to the hopper supports

1. Get a friend or two and lift the grate on top of the
hopper.
- The front end (with the slots) should be as shown, and the grate should be inside of the hopper on the other side (the side with the nuts).
- Have your friend hold the grate in place for the next step, or use C-Clamps to clamp the grate to the supports.
2. Bolt the grate to the hopper supports (1/2"x 2.5" bolt and lock nut). Bolt both loosely, and then tighten them.
- You'll need 2 washers on each side, as
the holes are slots and a 1/2" washer will
be too small to prevent the washer from

warping. Use a 3/4" washer as the other one.
- You may want to use a large nut in
place of a washer on the hopper
support side. (see photo)

## Step 10 — Install the grate supports

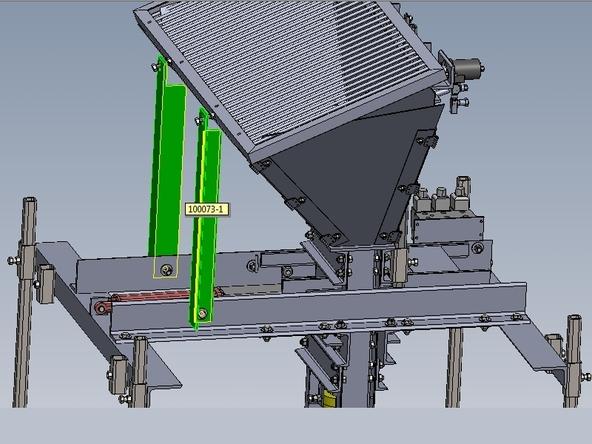
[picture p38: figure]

1. Loosely bolt the grate supports to the primary arms
2. Bolt (3/4"x2.5" bolt) The grate mounts through the hopper to the grate.
- Use a 3/4" washer where the bolt goes thru the grate support.
3. Tighten all bolts

## Step 11 — Re-install the shaker

1. Install the motor (http://makeprojects.com/Project/CEB-Shaker-Assembly/1728/1) (next section) on the shaker motor mount if you haven't already.
2. Place it on the bolts on the hopper supports.
- If for some reason it doesn't fit, torch away whatever metal is preventing it.
3. Tighten nuts onto it.

## Step 12 — Install the Dirt Deflector Plate

- Bolt it to the grate.

CEB Shaker Assembly

# CEB Shaker Assembly

Sketchup Model (http://sketchup.google.com/3dwarehouse/details?mid=98e197d560307fe81211da1f85706ccd)

Tools Needed:
- Allen Wrench
- Various Wrenches

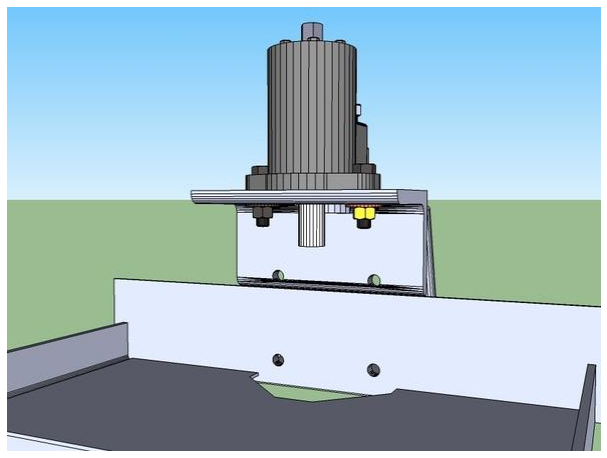
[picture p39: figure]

## Step 1 — Mount Motor

- Loosely bolt the assembled motor to the mount, as shown, using washers on both sides, and a lock washer touching the nut.

Materials Needed:
- Shaker Mount
- Shaker Motor
- Shaker Hammer and coupler
- 1" Pillow Block Bearings(2)
- 1/4"x2" Bolt (1)
- 3/8"x2" Bolts (4)
- 1/2"x2" Bolts (2)
- 3/8" Lock Nuts (4)
- 1/2" Lock Nuts (2)
- 3/8" Washers (8)
- 3/8" Lock Washers (4)
- 1/2" Washers (4)
- 1/2" Lock Washers (4)

CEB Shaker Assembly

## Step 2—Prepare Hammer and Shaft

1. Put the bearings onto the shaft, insuring the eccentric side is facing inwards.
- Remember to put the eccentrics in between the two bearings.
- The eccentrics are little collars with lopsided circles inside of them. This makes it so it can lock into the bearings.
- Insure both collars are facing the right direction (So it will lock onto the lip)
and so are the bearings.
- Put the coupler onto the shaft.
- Make sure you can see thru the holes, (it could be off 180 degrees and a little

crooked) then put on the bolt, lock washer, and lock nut. Tighten
2. Couple it to the motor, tightening down the set screw.

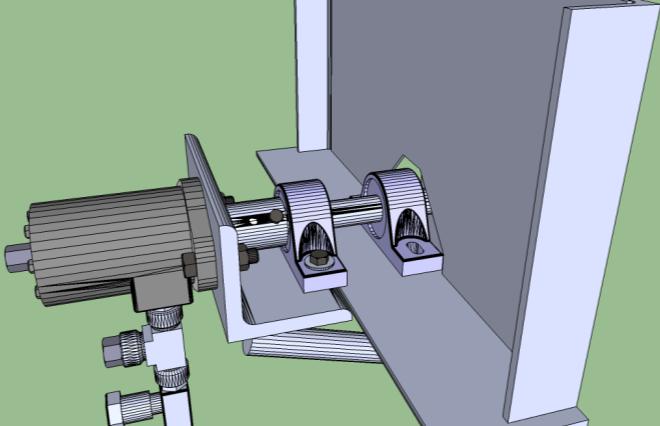
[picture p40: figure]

## Step 3 – Attach bearings

1. Tighten the motor mount bolts.
2. Bolt the bearing closest to the motor to the mount with a washers, a lock washer, and a lock nut. Tighten these down.
3. Insure the hammer rotates freely still.
- It may require some force, but shouldnt need much.
- If the hammer won't rotate, loosen the motor mount bolts, retighten them, and recheck it.
4. Position the other bearing and tighten it down, still insuring it will rotate without much force.
5. Lock the eccentrics by pushing them towards the lip on the bearing and twisting it.
6. Tighten the set screw on the eccentrics.

# CEB Assembly- Adjusting The Drawer

### See Videos:

- Adjusting the drawer (http://www.youtube.com/watch?v=xzoen7x46qI&feature=plcp&context=C25a19UDOEgsToPDskIAkvoB_CvbQhwcyvcZWDp5)
- Properly adjusted drawers (http://www.youtube.com/watch?v=cIkqryssZ7o&list=UUjvBN1r7UXXqmIbx_u7bIAw&index=214&feature=plpp_video)

### Tools Needed: - Mallet - Various Wrenches

### Step 1 — Put the drawer in • Insert the drawer into the chamber as shown, in

### the fully retracted position. Its important that it

be in the right orientation.

### - The adjustment bolts should be lowered so

that the roller guides are below the rails.

### Materials Needed: - Assembled CEB - Soil Loading Drawer

# Step 2 — Align the rails with the

center of the v's in the rollers.

### - If for some reason the rails and the rollers aren't spaced properly (the guides need to be closer or further apart) remove one of the guides and switch out the spacer on it to one

that will space them properly.

### - If only one roller of the four is off, the guide is

not parallel with the drawer.

### - Try tightening the nut that attaches

the rollers to the frame.

### - If that doesn't work, you might have welding spatter or something

between the guide and the frame. Remove it and check.

### - If none of the above steps make all the rollers

align, your drawer is likely flawed.
- The rails are probably not parallel.

### Take the drawer out and double check by measuring the separation of the rails. If they aren't parallel, see this

page. (http://opensourceecology.org/wiki/CEB_Press/Manufacturing_Instructions/Soil_loading_drawer)

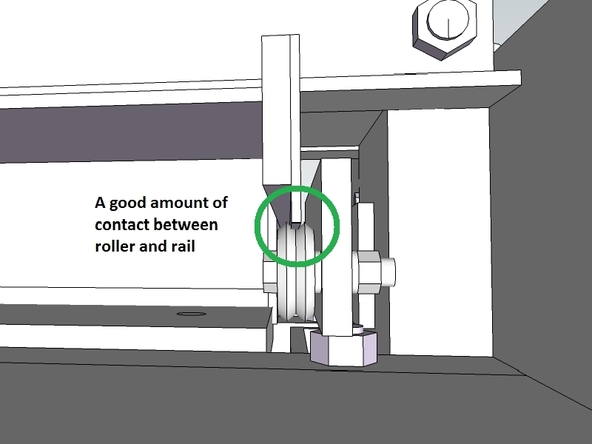
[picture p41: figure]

# Step 3 — Tighten the rollers against

### the rails • Tighten the adjustment bolts so they push the rollers up

to the rail, so all of the rollers are contacting the rails.
- The two should be touching snugly, but not forcefully.

# Step 4 — Move the drawer and re-adjust bolts

- Move the drawer to the fully extended position.

### - The drawer will likely get stuck along some points of its travel. Its OK to hit it with a hammer. Remember the secondary cylinder

will be applying tons of force to move it.

### - If you need to hammer it REALLY hard, either your drawer is hitting something, or the rollers are too tight on the rails. Investigate

the cause.

### - When the drawer is in position, check the rollers

again. They should all still be touching the rails.

### - If one is below the rail, tighten the bolt so the

rail and roller are touching.

Step 5 — Slide the drawer in and out • You will likely need to try sliding it in and out a few times before you can find the perfect amount of adjustment.
- Keep checking the contact as you slide it out.
- Your work is done when you can slide the drawer in and out and the rails stay on the roller the whole time.
- Using a hammer is OK, but if you have to use too much force something is wrong.

CEB Assembly – Installing the Secondary Cylinder (A5)

# CEB Assembly – Installing the Secondary Cylinder

Tools Needed:

- Various Wrenches
- Welder
- Hole Puncher

## Step 1 — Mark the center between the primary

arms on the secondary arm.
- This is on the opposite side of the CEB of the brickholder plate.

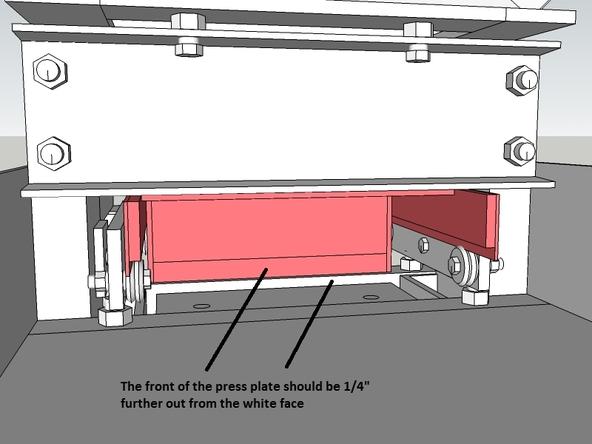
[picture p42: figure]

## Step 2 — Position the drawer

- The drawer needs to be in the fully retracted position.
- This is when the drawer is about to eject the brick, the press plate will be back 1/4" from the inside of the compression chamber.

Materials Needed:
- Assembled CEB
- Secondary Cylinder
- Prepared secondary cylinder hydraulics
- ½”x3” Flat – 3”(1)

CEB Assembly – Installing the Secondary Cylinder (A5)

Step 3 — Prepare the cylinder mount.
- Punch a 1" hole in the center of a 3"x3" piece of 1/2" thick steel.

## Step 4 — Place the cylinder

- The base of the cylinder attaches to the secondary cylinder. The side of the cylinder with the rod attaches to the drawer.
- On the side which attaches to the secondary arm, put the pin through the mount, a 1" washer, and the cylinder.
- Both sides will need a 1" washer to act as a spacer so the cylinder can't slide back and forth.
- When the cylinder is attached to the drawer, place the mount on your center mark.
- Square the mount in all directions.

## Step 5 — Weld the mount in place

1. Tack the mount in a few places.
2. Remove the pin and move the cylinder out of the way of the mount.
- You can slide the drawer away so you don't need to remove that side.
3. Weld the mount solid, all the way around. Make sure it stays square.

CEB Assembly – Installing the Secondary Cylinder (A5)

## Step 6 — Install hoses

1. Return the secondary cylinder and re-mount it. Don't forget the washer.
2. Remove the plug from the port on top of the cylinder. The cylinder may have fluid in it, so keep a jar handy to catch any that spills.
3. Install Assembly #2 into this port.
4. Couple the remaining assemblies and hoses in place.

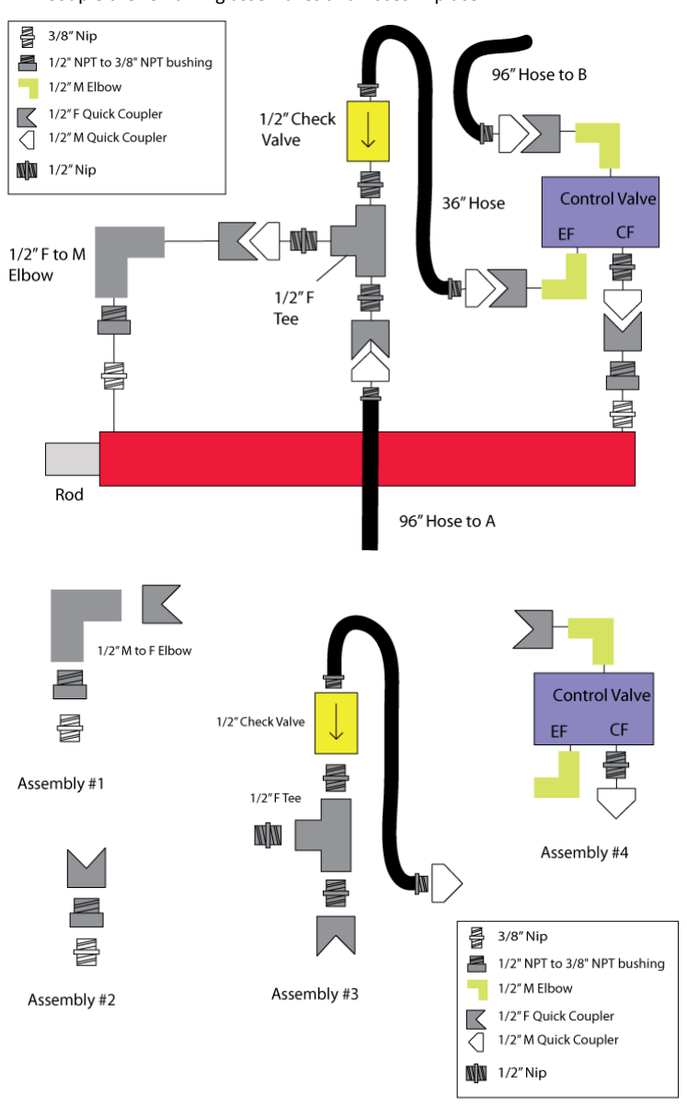
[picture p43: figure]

CEB Hardlining the Main Cylinder

# CEB Hardlining the Main Cylinder

Tools Needed:
- Various Wrenches
- Thread tape

## Procedure

1. Remove the couplers and hex nipples at the elbow using a wrench.
2. Tighten the hoses (with thread tape) into the elbows.

Materials Needed:
- ½”x56” Hydraulic Hose (2)

CEB Painting the Machine

# CEB Painting the Machine

## Procedure

1. Cover the hydraulics and any other place that should not be painted.
2. Check all external surfaces for sharp edges and smooth with angle grinder.
3. Remove any surface rust with wire brush and / or sandpaper.
4. Apply a thorough coating of paint to all steel surfaces.
5. Allow 24 hours to dry before handling.

CEB Electronics – Linked Extension Cord

# CEB Electronics – Linked Extension Cord

See video (http://vimeo.com/33327725) first.

Tools Needed:
- Straight Pattern Tin Snips | • Extension Cord of 50 feet (about
- Wire Strippers Compatible with 16 Gauge | 15 meters) having 16 Gauge
- Crimpers Compatible with 16 to 22 Gauge Connectors | Wires
- Measuring Tape | • Female Insulated Electrical
- Handiworks | Connector for 16 to 22 Gauge
- Compatible Set of a Soldering Iron and Solder | • Battery Alligator Clips (2)
- Soldering Stand
- Wet Sponge or Wet Paper Towel

## Procedure

1. Using the tin snips, cut the extension cord such that the male cord is 6 feet in length. The cutting tolerance is 8”.
2. Using the tin snips, strip the loose sleeves of the male and female cords such that 12” of insulated wires are unsleeved. The stripping tolerance is 2”.
3. Using the tin snips, cut the green wire of the male and female cords such that none or little of the green wire is visible. The cutting tolerance is 1.25”.
4. Using the wire strippers, strip the white and black wires of the male and female cords by 0.75”. The stripping tolerance is 0.25”.
5. Using the crimpers, crimp the female connector onto the white wire of the male cord. Insure that no exposed wire lies between the wire insulation and the connector insulation.
6. Insert 1 alligator clip insulation into each of the white and black wires of the female cord.
7. Using the soldering set, solder the white and black wires of the female cord to the alligator clips.
8. Slide the inserted insulation pieces over the alligator clip handles.
9. Link the male and female cords together by their plugs.

Materials Needed:

CEB Electronics – Sensor Unit

# CEB Electronics – Sensor Unit

See video (http://vimeo.com/33754777) first.

Tools Needed:
- Compatible Set of Soldering Iron and Solder | • Hall Effect Sensor
- Soldering Stand | • 1.5m of 4 Wire Underground
- Wet Sponge or Wet Paper Towel | Telephone Cable
- Straight Pattern Tin Snips | • Silicone
- Wire Strippers Compatible With 22 Gauge Wire | • [3] 3cm lengths of Shrink Tubing
- Heat Gun | • PVC Pipe with 2.5cm Outer
- Pliers | Diameter, 1.5cm Inner Diameter,
- Helping Hand | 9cm Length
- Measuring Tape
- Wire Strippers Compatible With 8 Gauge Wire

## Procedure

1. Using the tin snips, cut the sleeve of the telephone wire by 5cm and 20cm at both ends. The cutting tolerance is 2cm.
2. Using the tin snips, cut the orange-white wire at both ends of the telephone wire.
3. Using the wire strippers, strip the bluewhite, blue, and orange wires of the telephone wire by 2cm at the 5cm end and by 1cm at the 20cm end. The stripping tolerance is 0.5cm.
4. Insert 3cm shrinktubing into the 5cm blue, blue-white, and orange wires.
5. Bend the sensor prongs and the exposed metal of the 5cm wires into hooks such that the 3 prong hooks can latch onto the 3 wire hooks to facilitate soldering. Use pliers to pinch the hook connections during the soldering process.
6. Using the soldering set and the helping hand, solder the hall-effect sensor prongs to the 5cm wires. The orientation of the soldering connections is such that, when you can see the sensor text and its prongs pointing downward, from left to right the colour of the wires to be soldered are: bluewhite (for 5V+), blue (for GND), and orange (for Signal).
7. Using the heat gun, cover the soldered prong-to-wire connections with the shrinktubing then apply heat to the now-covered connections. The shrinktubing should shrink, forming a tight insulating seal for each of the prong-to-wire connections.
8. Pour the silicone into the tube such that the tube is completely filled in.
9. Insert the wired hall-effect sensor into the PVC tube leaving 2cm of space at the non-insertion end of the tube.
10. Gently set the sensor unit on a flat surface and wait 24 hours for the silicone to cure.

Materials Needed:

CEB Electronics- Solenoid Driver

# CEB Solenoid Driver

This is a complicated step. See the wiki (http://opensourceecology.org/wiki/CEB_Press/Manufacturing_Instructions/Detroit_Fab_Lab_Solenoid_Driver_v2) for troubleshooting and additional techniques or upgrades.

## Procedure

1. Either mill your board using this model, (http://sketchup.google.com/3dwarehouse/details?mid=10a3722997daf166b38804396e417a9b) OR complete the remainder of this step.

## 1) Print the image on the right on laser photo paper, with dimensions of 3”x4.5.”

2) Tape the paper onto the copper board.

## 3) Using a laundry iron, heat the paper until

discolored.
4) Soak in water and peel the paper away.

## 5) Agitate in pcb etchant solution for 20-30 min

until copper is gone.

## 6) Apply accetone to a cloth and wipe away

toner.
7) Check and fix errors.

## - Places where not enough was etched away or where too much was. Can fix

by soldering or sanding.

Materials Needed:
Description | Qty.
Power N MOSFET | 5
Green LED | 7
Diode | 5
499 Resistor | 5
49.9k Resistor | 5
10k Resistor | 2
2 Pos Terminal | 9
reset switch | 1
6 Pos Header | 2
8 Pos Header | 2
PCB | 1
100 Resistor | 2

Tools Needed:
- Oxide Remover Solution - Ex. Isopropyl
- Masking Tape
- Etching Solution - Ex. Ferric Chloride
- Toner Removal Solution - Ex. Acetone
- Glass Bowl that fits 3" x 4.5" area dimensions with at least 1" depth
- Paper towel
- Compatible Set of Computer and Laser Printer with Glossy Paper
- Laundry Iron
- Drill Press with Number 58 Twist Drill Bit
- Compatible Set of Soldering Iron, Low-diameter Solder, Flux and Brush, Soldering Stand, and Wet Sponge or Wet Paper Towel

CEB Electronics- Solenoid Driver

2. Drill the etched board at the two rows of small grey squares where the pins would be (28 holes) and all grey circles of where the screw terminals would be (18 holes) as shown in the following diagram.

## 3. Surface-mount solder the etched and drilled copper clad board with the complete board

diagram above. The 6 POS Headers go in the top drilled holes, and the 8 POS Headers go in the bottom holes.

CEB Electronics – Case

# CEB Electronics – Case

See video (http://vimeo.com/33580858) first.

## Procedure

1. Open the lug box
2. Using the screwdriver and the half inch flathead bit, unscrew and remove the terminal components inside the lug box
3. Using the safety glasses, hammer and the centre punch, remove the inner lids at the bottom-left, bottom-middle, bottom-right, and right-bottom of the lug box
4. Mount the two wire clamps onto the bottom-left and right-bottom holes of the lug box
5. Mount the toggle switch onto the bottom-right hole of the lug box; in the process, put the 3.2cm OD washers on both sides of the lug wall.
6. Using the crimper, crimp the small ring connector and the male connector onto the two ends of the fuse holder; then insert the buss fuse.
7. Using the crimper, crimp the ring connector to the black wire of the male end of the linked extension cord.

Materials Needed:
- Outdoor Main Lug Box
- [2] Wire Clamps
- Toggle Switch
- [2] 3.2cm OD, 1.27cm ID Washers (1/2” Washer)
- Fuse Holder
- Male Insulated Connector for 10-12 Gauge Wire
- Ring Insulated Connecter with Small Hole for 10-12 Gauge Wire
- 10 Amp Buss Fuse
- Ring Insulated Connector for 10-12 Gauge Wire
- [2] 12cm by 7.5cm by 0.4cm high density polyethylene plate
- [4] M3 machine screws of 20mm length
- [4] M3 nylon-threaded lock nuts
- [4] 8-32 machine screws of 3/4 inch length
- [7] 8-32 machine screws of 3/8 inch length
- Arduino Uno Microcontroller
- Arduino Uno Serial Issue Solution, Replies 2 and 4 (http://arduino.cc/forum/index.php/topic,52447.0.html) Note: for Arduino Uno Version R2, the contact point for entering DFU mode is the top-left male pin instead of the top-left pad. You'll need to perform this solution method if initial serial communication tests prove buggy. You cannot perform this after mounting the microcontroller inside the case.
- Linked Extension Cord (from prior guide)

Tools Needed:
- Screwdriver with the following bits: Quarter Inch Flathead, Half Inch Flathead, Number 1 Phillips, and Number 2 Phillips
- Hammer
- Centre Punch
- Crimper
- Cordless Drill with the following twist drill bits: 9 by 64 inch, 1 by 8 inch, 3 by 16 inch
- Needlenose Pliers
- Electrical Tape
- Tap Wrench with 8-32 Tap

CEB Electronics – Case

8. Using the safety glasses, cordless drill and the 9 by 64 inch drill bit, drill holes on the first plastic plate such that 5 terminal holes are approximately evenly spaced along an axis near the top edge, and such that 2 terminal holes are located near the bottom corners.
9. Using the safety glasses, cordless drill and the 1 by 8 inch drill bit, position the Arduino microcontroller board on a second plastic plate then drill through the board mounting holes through the plastic such that the holes of the board and those of the plastic align. Use M3 Machine Screws to help align the drilled holes during the process. Be careful not to excessively ream the Arduino board.
10. Using the safety glasses, cordless drill, and the 3 by 16 inch drill bit, drill 2 mounting holes near the far edges of the first and second plastic plates.
11. Using the safety glasses, cordless drill, and the 9 by 64 inch drill bit, drill holes on the back of the lug box such that they align with the mounting holes of the first and second plastic platforms. The Arduino platform should be positioned closer to the top than the terminal platform. Leave enough room surrounding the edges of the platforms to facilitate assembly, disassembly, and wiring.
12. Using the metal file, deburr the lug box's platform mounting holes.
13. Using the tap wrench and the 8-32 tap, tap the 7 terminal holes of the terminal platform and the 4 platform mounting holes of the lug box.
14. Using the screwdriver with the number 1 phillips bit and pliers, mount the Arduino microcontroller board onto the Arduino platform through the 4 mounting holes with the 20mm M3 machine screws and the 4 M3 nylon-threaded lock nuts.
15. Using the screwdriver with the number 2 phillips bit, mount the Arduino platform and the terminal platform onto the back of the lug box by screwing the 3 by 4 inch length 8-32 machine screws through the 4 mounting holes. Use 1/2-13 nuts to act as spacers between the platforms and the back of the lug box. The arduino platform should be mounted closer to the top of the lug box than the terminal platform.
16. Insert the non-clip end of the linked extension cord into the lug box through the bottom-left hole, then connect the black wire's female connector to the fuse holder's male connector. Wrap electrical tape around the exposed male-female connection and put a small fold at the end of the tape piece for ease of disassembly.
17. Using the screwdriver with the number 2 phillips bit, connect the fuse holder's ring connector to one terminal of the toggle switch. Then connect the linked extension cord's black wire ring connector to the bottom-right screw terminal on the terminal platform.
18. Using the screwdriver with the number 2 phillips bit, tighten the screws of the wire clamp at the bottom-left of the lug box.

CEB Electronics – Controller Box

# CEB Electronics- Controller Box

See Video (http://vimeo.com/33885023)

Tools Needed:
- Straight Pattern Tin Snips | • Case
- Wire Strippers Compatible with 18 and 22 Gauge | • [2] Sensor Units
- Crimpers | • Solenoid Driver v2
- 2.3mm Flathead Screwdriver | • 18 Gauge Red Wire
- Screwdriver with Number 2 Philips Bit | • 18 Gauge Black Wire
- Needlenose Pliers | • Ring Insulated Connector with
- Measuring Tape | Small Hole for 10-12 Gauge
| • [14] Ring Insulated Connectors

## Procedure

1. Mount the solenoid driver on top of the Arduino microcontroller.
2. Using the tin snips, cut 6 pieces of 20cm black wire, 2 pieces of 20cm red wire, 5 pieces of 1.5m black wire, and 1 piece of 1.5m red wire.
3. Using the wire strippers at 22 gauge, strip half a centimetre at one end of the 6 pieces of 20cm black wire and 1 piece of 20cm red wire.
4. Using the wire strippers at 18 gauge, strip a centimetre at the other ends of the 6 pieces of 20cm black wire and the 1 piece of 20cm red wire, as well as both ends of the other 1 piece of 20cm red wire, the 5 pieces of 1.5m black wire, and the 1 piece of 1.5m red wire.
5. Using the crimper, crimp the 10 to 12 gauge ring insulated connector at one of the 1 centimetre stripped ends of the 6 pieces of 20cm black wire, the 2 pieces of 20cm red wire, the 5 pieces of 1.5m black wire, and the 1 piece of 1.5m red wire.
6. Also crimp the 10 to 12 gauge small hole ring insulated connector at the remaining 1cm end of the 20cm red wire and crimp the 14 to 16 gauge ring connector to the remaining 1cm ends of the 5 pieces of 1.5m black wire and 1 piece of 1.5m red wire.
7. Using the screwdriver with the number 2 philips bit, connect the small ring end of the 20cm red wire to the remaining power switch terminal.
8. Insert the large ring end of the 6 1.5m wires through the bottom-middle hole of the lug box.
9. Using the screwdriver with the number 2 philips bit, connect the large ring end of the 1.5m red wire, the remaining ring end of the switch-connected 20cm red wire, and the ring end of the other 20cm red wire to the bottom-left screw of the terminal platform.
10. Connect the large ring end of the 5 1.5m black wires and the ring end of 5 20cm black wires to the top 5 screws of the terminal platform. Then connect the ring end of the remaining 20cm black wire to the bottom-right screw of the terminal platform.
11. Using the flathead screwdriver, connect the half centimetre ends of the 6 pieces of 20cm black wire to the lower terminal of the 5 mosfet terminal blocks, and the left terminal of the power terminal block. Note that the mosfet connections from left to right on the terminal platform should go from bottom to top on the solenoid driver. Also connect the half centimetre end of the 1 piece of 20cm red wire to the right terminal of the power terminal block.

Materials Needed:

for 10-12 Gauge
- [6] Ring Insulated Connectors for 14-16 Gauge

CEB Electronics – Controller Box

12. Insert the 2 sensor units by their wire end into the right-bottom hole of the lug box.
13. Using the flathead screwdriver, connect the bluewhite wires, orange wires, and blue wires into the top, middle, and bottom terminal blocks, respectively, on the right side of the solenoid driver.
14. Using the screwdriver with the number 2 philips bit, screw-tighten the wire clamp at the right-bottom hole of the lug box.

CEB Mount Solenoid Valve Set and Controller Box

# CEB Mount Solenoid Valve Set and Controller Box

The CEB Assembly video also shows how to do this step. Note that the video is different than the written instructions in that they use quick couplers whereas the written instructions do not.

## Install Controller

1. Bolt Controller Box to Controller Mount
2. Bolt controller mount to CEB.
3. Power clamp the sensor that has its orange (signal) wire in Arduino pin A0 (aka pin 14) next to the primary cylinder bar.
- Attach 3 magnets to the primary cylinder bar such that they are vertically aligned and their terminals are reversing ex. NSN or SNS.
- Space the magnets approximately 5cm apart. Change the magnet positions during testing to achieve the

Materials Needed:
- 3/4" Quick Coupler Set (1)
- SAE 12M to 3/4" Swivel (2)
- SAE 6M to 1/2" Swivel (6)
- Bolts and nuts for mounting on valve mount and
controller
- 3/4"x1.5" Bolts (4)
- 3/4" Nuts (4)
- Power Clamps (4)
- Rare Earth Magnets (6)
- Prepared Controller Box
- Prepared Controller Mount

Tools Needed:
- Various Wrenches

CEB Mount Solenoid Valve Set and Controller Box

desired soil loading position, maximum compression position, and press foot ejection position.

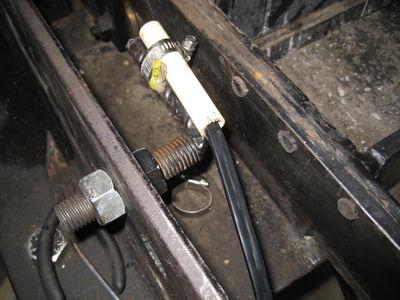
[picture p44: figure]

4. Power clamp the sensor that has its orange (signal) wire in Arduino pin A1 (aka pin 15) next to the secondary cylinder
and soil loading drawer.
- Attach 3 magnets to the soil loading drawer such that they are vertically aligned and their terminals are reversing ex. NSN or SNS.
- Space the magnets approximately 5cm apart. Change the magnet positions during testing to achieve the desired soil loading position, compression position, and maximum ejection position.

## Prepare Solenoid

1. Install the solenoid valves on the manifold in the order C-C-H, going from left to right, with the ports at the top.
2. Install the quick connect inlet and outlet in the side ports on the manifold. DON'T use thread tape for any connections to the manifold.
3. Onto the top of the manifold, install the 6 swivel fittings into the ports.

## Install Solenoid on Machine

1. Bolt the solenoid to the valve mount.
2. Bolt the solenoid and valve mount to the primary arms on the assembled CEB.
3. Attach hoses from cylinders and shaker to manifold. See illustration for number locations.
- 1=Main Cylinder Top
- 2=Main Cylinder Bottom
- 3=Secondary Cylinder Tee
- 4=Secondary Cylinder Control Valve
- 5=Shaker Non Return Line
- 6=Shaker Return Line (Side with Needle Valve and Tee)

CEB Electrohydraulic Integration

# CEB Electrohydraulic Integration

See video (http://vimeo.com/34045315) first. Note that this process should occur only if the solenoid valve set and controller box are already mounted on the CEB press. The process is shown separately from the CEB press for clarity.

## Wiring Diagram

## Procedure

1. Using the tin snips, cut 2 pieces of 30cm red wire.
2. Using the wire strippers, strip 1cm at all ends of the 2 pieces of red wire.
3. Using the crimpers, crimp the ring connectors at all ends of the 2 pieces of red wire.

Materials Needed:
- Controller Box
- Ensure that the connections between the top 5 terminals of the terminal platform and the left 5 (MOSFET) terminals of the solenoid driver are such that left to right (terminal platform) corresponds with bottom to top (solenoid driver), respectively. In this case, from left to right the top terminals of the terminal platform are indirectly connected to Arduino pins 11, 10, 9, 6, and 3, respectively.
- Solenoid Valve Set
- Ensure that the solenoid valves are mounted to the subplate such that, when the work ports open away from you, from left to right the solenoid valve types are C, C, and H, respectively.
- 18 Gauge Red Wire
- [4] Ring Insulated 14-16 Gauge Connectors

Tools Needed:
- Screwdriver with Number 2 Philips Bit
- Straight Pattern Tin Snips
- Wire Strippers compatible with 18 gauge
- Crimper
- 10mm Hex Key
- Measuring Tape

CEB Electrohydraulic Integration

4. Orient the solenoid valve set such that its work ports open away from you.
5. Using the hex key, unscrew the 3 hex caps closer to you.
6. Using the screwdriver with the number 2 philips bit, unscrew and remove the lids of the solenoid valve electronics.
7. Ensure and relocate if necessary the solenoid valve jumpers such that each solenoid valve has its left-middle and left-top terminals linked.
8. Screw the small ring end of the long red 1.5m wire to the left-top terminal of the rightmost solenoid valve.
9. Screw the small ring ends of the 30cm red wire to the left-middle terminal of the rightmost solenoid valve and the left-top terminal of the middle solenoid valve.
10. Screw the small ring ends of the other 30cm red wire to the left-middle terminal of the middle solenoid valve and the left-top terminal of the leftmost solenoid valve.
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

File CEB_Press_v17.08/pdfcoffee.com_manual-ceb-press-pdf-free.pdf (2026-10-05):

## Manual CEB Press/Design

### Contents

- 1 NORTH AMERICAN VERSION (http://www.osrliving.org/wiki/index.php?title=Manual_CEB_Press/Design#NORTH_AMERICAN_VERSION)
- 2 Features (http://www.osrliving.org/wiki/index.php?title=Manual_CEB_Press/Design#Features)
- 3 Mechanical Drawings (http://www.osrliving.org/wiki/index.php?title=Manual_CEB_Press/Design#Mechanical_Drawings)
- 4 Images (http://www.osrliving.org/wiki/index.php?title=Manual_CEB_Press/Design#Images)
- 5 METRIC VERSION (http://www.osrliving.org/wiki/index.php?title=Manual_CEB_Press/Design#METRIC_VERSION)
- 6 Mechanical Drawings (http://www.osrliving.org/wiki/index.php?title=Manual_CEB_Press/Design#Mechanical_Drawings_2)
- 7 Images (http://www.osrliving.org/wiki/index.php?title=Manual_CEB_Press/Design#Images_2)

### NORTH AMERICAN VERSION
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

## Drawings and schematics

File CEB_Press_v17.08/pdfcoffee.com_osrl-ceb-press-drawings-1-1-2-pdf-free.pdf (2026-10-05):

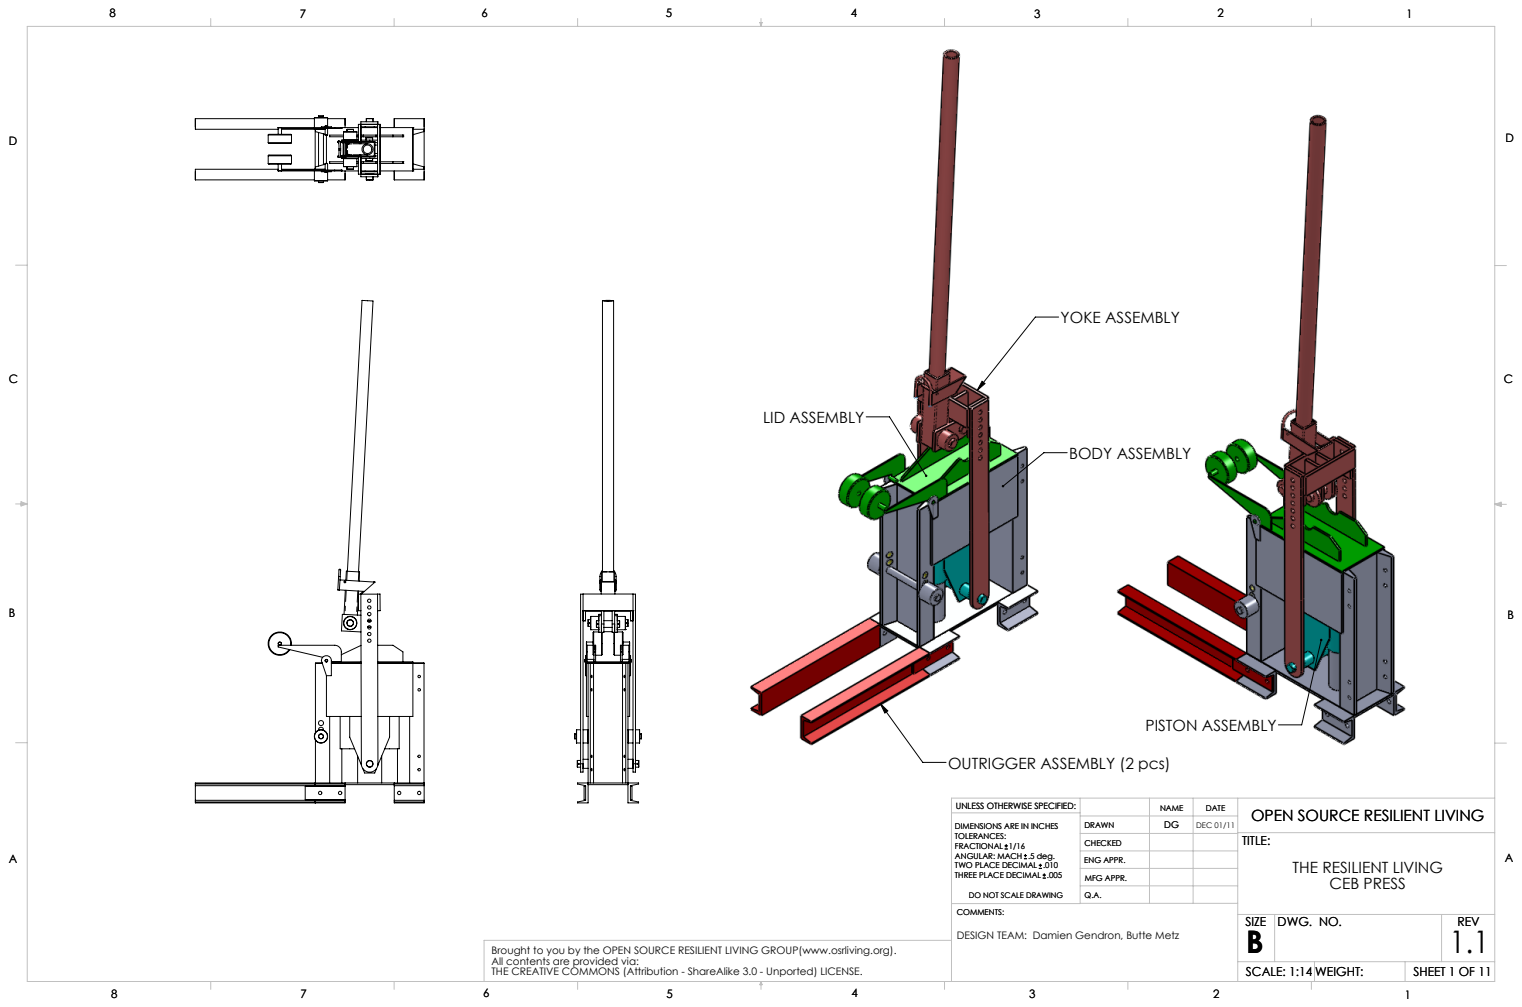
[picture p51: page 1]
PISTON ASSEMBLY; BODY ASSEMBLY; YOKE ASSEMBLY; LID ASSEMBLY; ENG APPR.; MFG APPR.; DWG. NO.; REV; SCALE: 1:14 WEIGHT:; SHEET 1 OF 11; DEC 01/11

OUTRIGGER ASSEMBLY (2 pcs)

UNLESS OTHERWISE SPECIFIED:

OPEN SOURCE RESILIENT LIVING
TITLE:
THE RESILIENT LIVING
CEB PRESS

DIMENSIONS ARE IN INCHES
TOLERANCES:
FRACTIONAL 1/16
ANGULAR: MACH .5 deg.
TWO PLACE DECIMAL .010
THREE PLACE DECIMAL .005

DO NOT SCALE DRAWING
COMMENTS:
DESIGN TEAM: Damien Gendron, Butte Metz

Brought to you by the OPEN SOURCE RESILIENT LIVING GROUP(www.osrliving.org).
All contents are provided via:
THE CREATIVE COMMONS (Attribution - ShareAlike 3.0 - Unported) LICENSE.

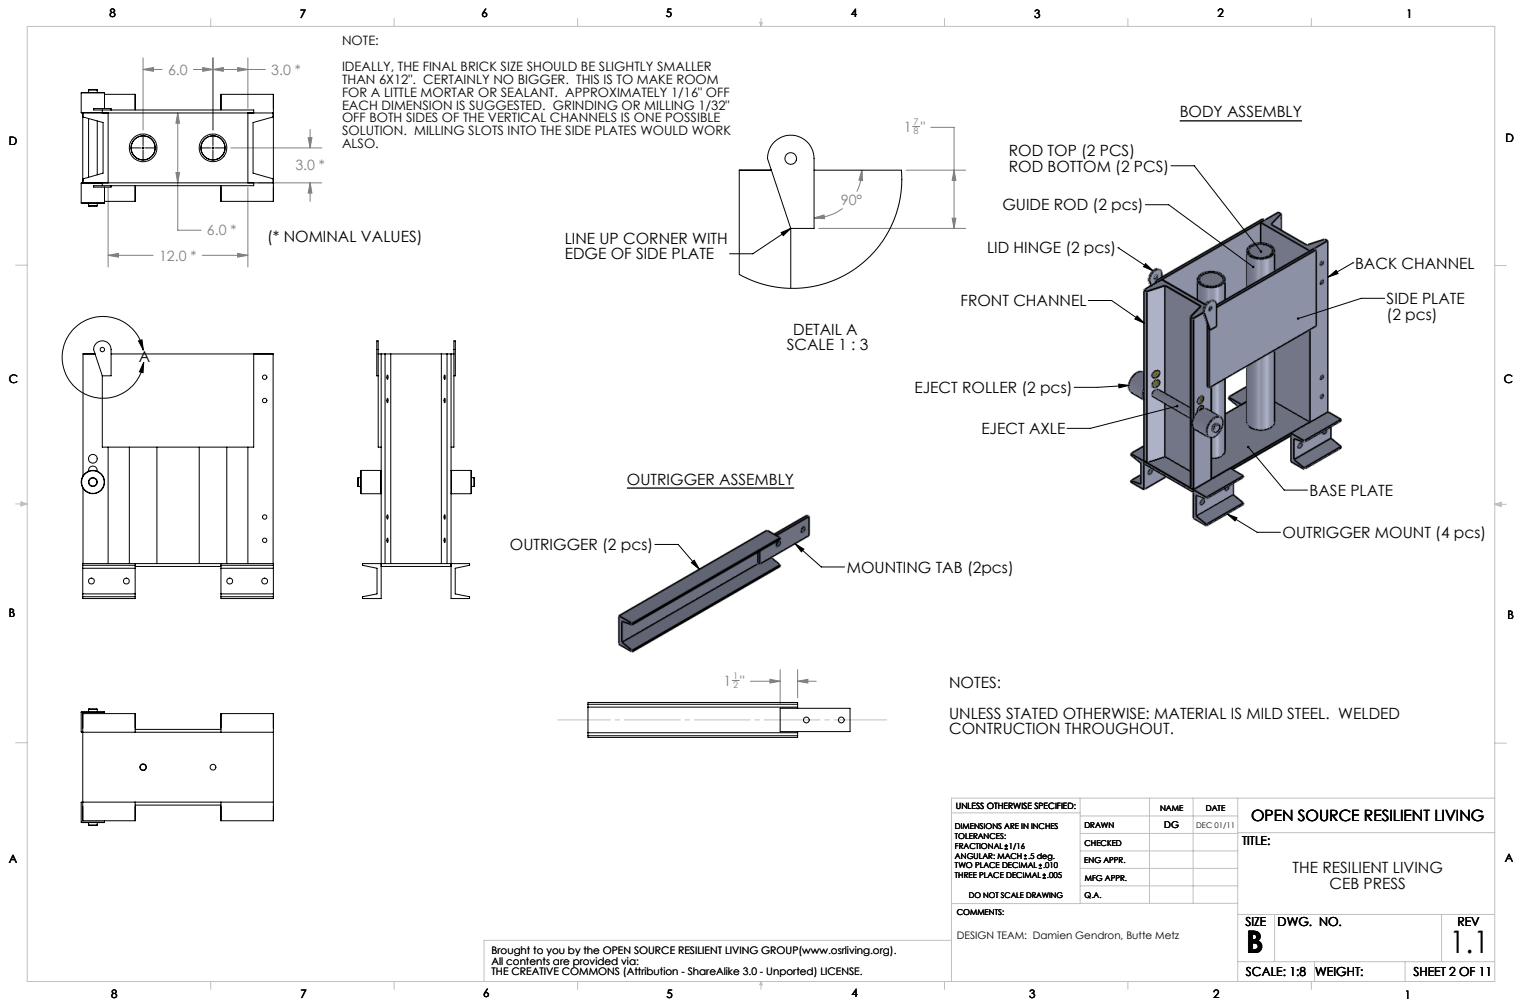
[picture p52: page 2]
OUTRIGGER ASSEMBLY; BACK CHANNEL; SIDE PLATE (2 pcs); EJECT AXLE; FRONT CHANNEL; BASE PLATE; (* NOMINAL VALUES); DETAIL A SCALE 1 : 3; BODY ASSEMBLY; OUTRIGGER (2 pcs); MOUNTING TAB (2pcs); ENG APPR.; MFG APPR.; DWG. NO.; REV; SCALE: 1:8 WEIGHT:; DEC 01/11

NOTE:
IDEALLY, THE FINAL BRICK SIZE SHOULD BE SLIGHTLY SMALLER
THAN 6X12". CERTAINLY NO BIGGER. THIS IS TO MAKE ROOM
FOR A LITTLE MORTAR OR SEALANT. APPROXIMATELY 1/16" OFF
EACH DIMENSION IS SUGGESTED. GRINDING OR MILLING 1/32"
OFF BOTH SIDES OF THE VERTICAL CHANNELS IS ONE POSSIBLE
SOLUTION. MILLING SLOTS INTO THE SIDE PLATES WOULD WORK

ROD TOP (2 PCS)
ROD BOTTOM (2 PCS)
GUIDE ROD (2 pcs)

LINE UP CORNER WITH
EDGE OF SIDE PLATE

LID HINGE (2 pcs)

EJECT ROLLER (2 pcs)

OUTRIGGER MOUNT (4 pcs)

NOTES:
UNLESS STATED OTHERWISE: MATERIAL IS MILD STEEL. WELDED
CONTRUCTION THROUGHOUT.

UNLESS OTHERWISE SPECIFIED:

OPEN SOURCE RESILIENT LIVING
TITLE:
THE RESILIENT LIVING
CEB PRESS

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

DO NOT SCALE DRAWING
COMMENTS:

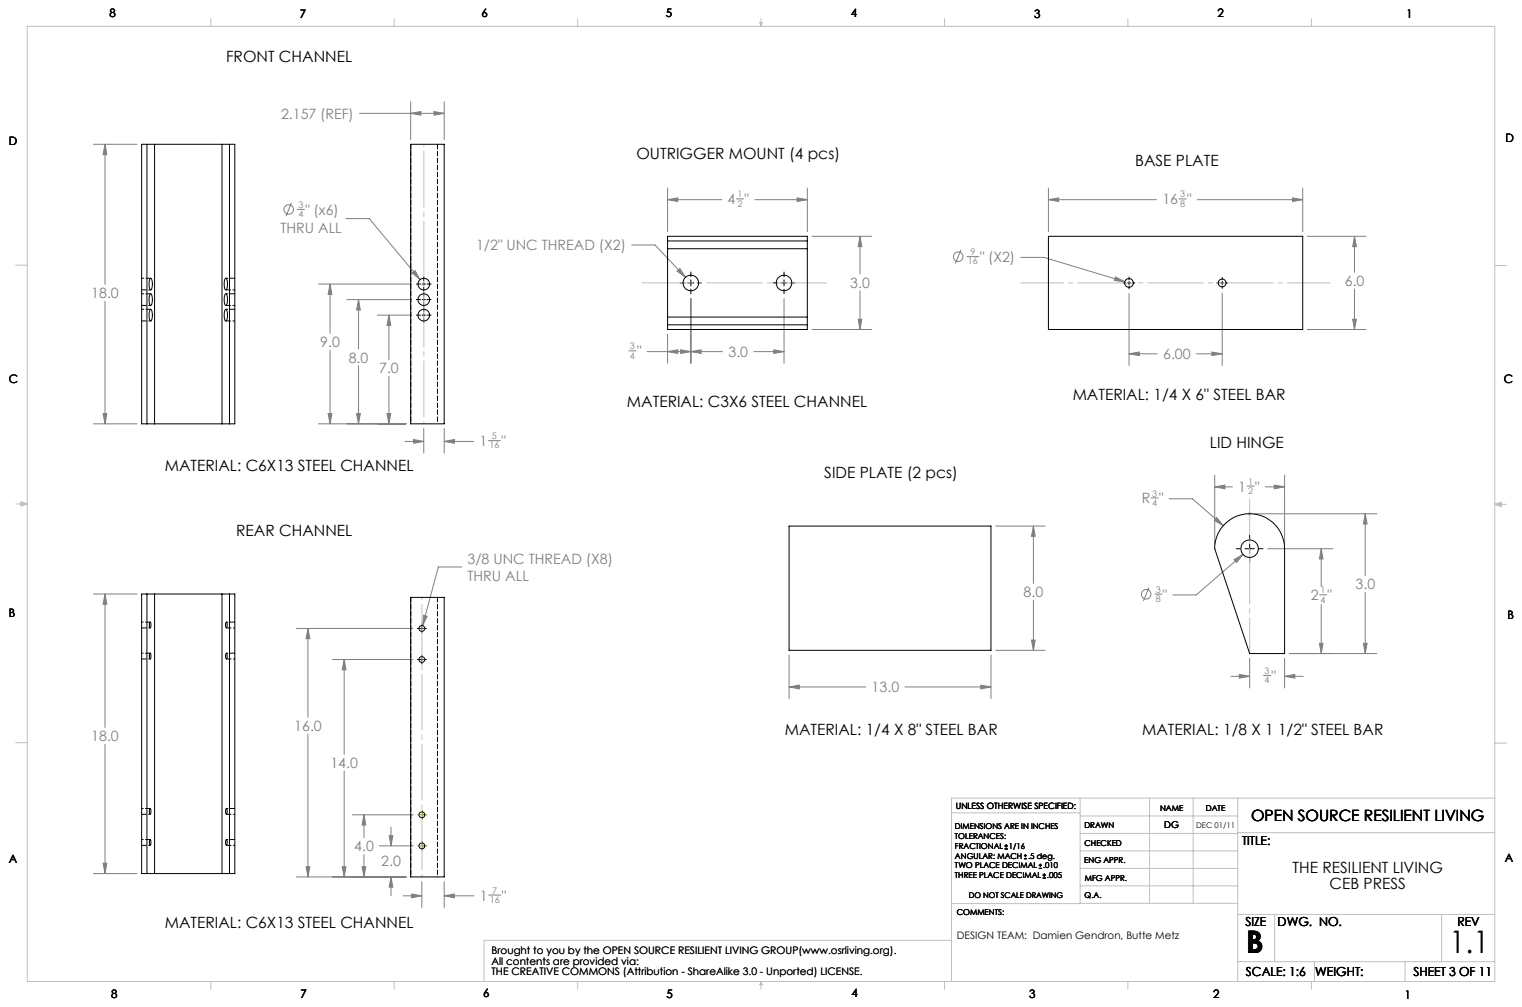
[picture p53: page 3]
4 " (x6) THRU ALL; 2.157 (REF); THRU ALL; 3/8 UNC THREAD (X8); BASE PLATE; 1/2" UNC THREAD (X2); MATERIAL: 1/4 X 8" STEEL BAR; MATERIAL: 1/8 X 1 1/2" STEEL BAR; FRONT CHANNEL; REAR CHANNEL; LID HINGE; ENG APPR.; MFG APPR.; DWG. NO.; REV; SCALE: 1:6 WEIGHT:; DEC 01/11

OUTRIGGER MOUNT (4 pcs)

MATERIAL: C3X6 STEEL CHANNEL

MATERIAL: 1/4 X 6" STEEL BAR

MATERIAL: C6X13 STEEL CHANNEL

SIDE PLATE (2 pcs)

UNLESS OTHERWISE SPECIFIED:

OPEN SOURCE RESILIENT LIVING
TITLE:
THE RESILIENT LIVING
CEB PRESS

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

DO NOT SCALE DRAWING
COMMENTS:

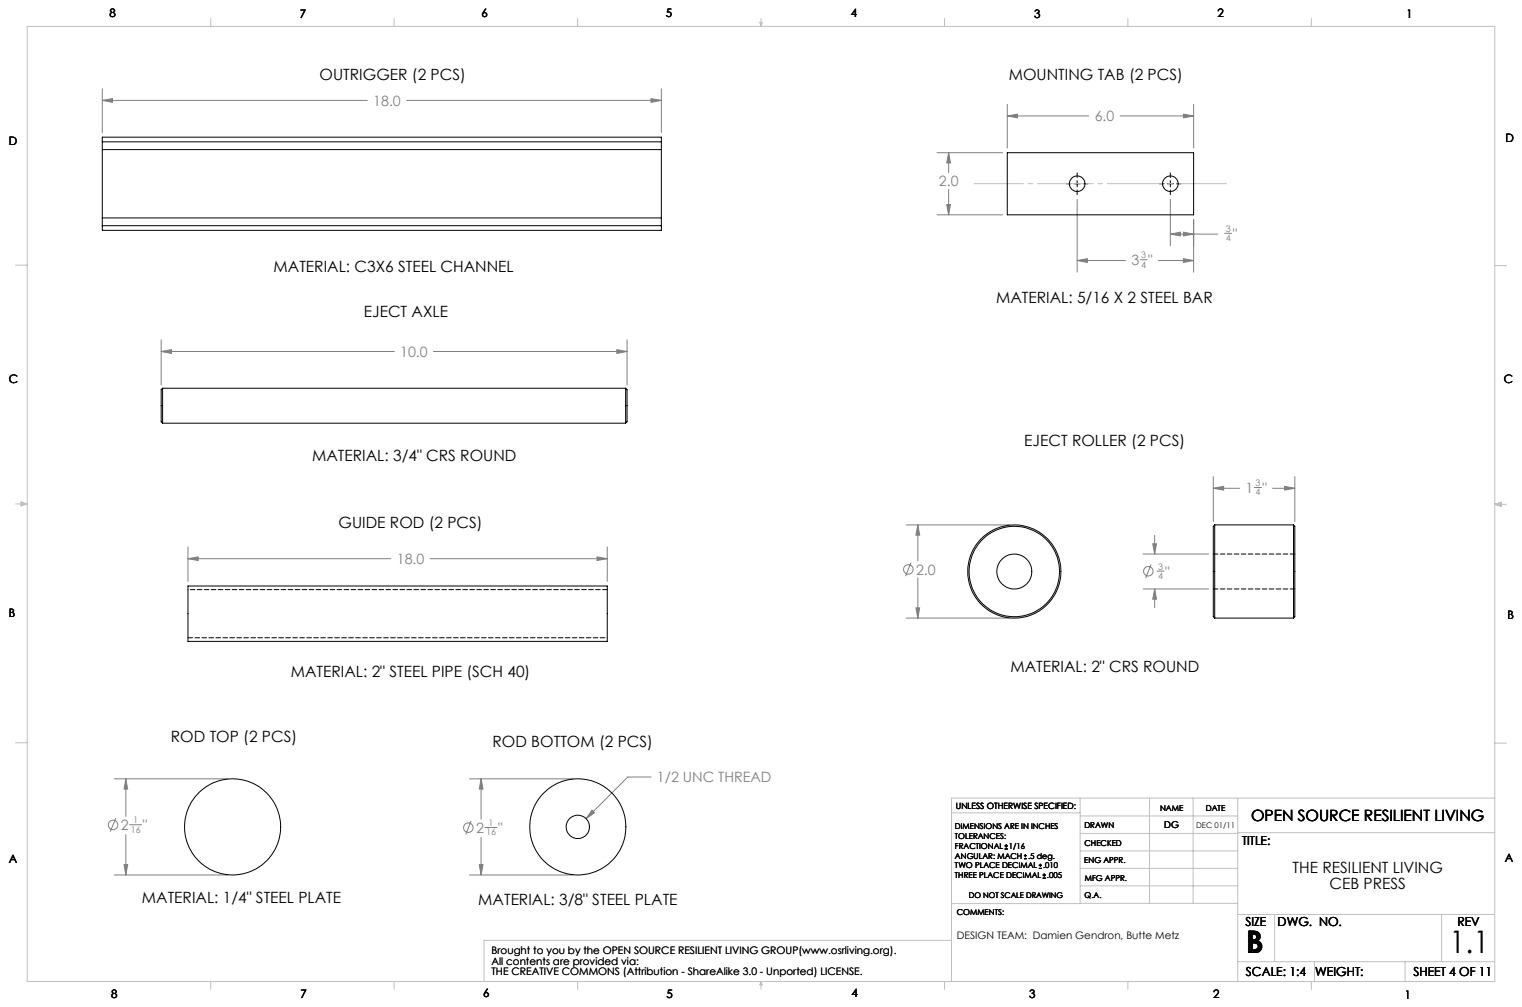
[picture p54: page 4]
EJECT AXLE; 1/2 UNC THREAD; OUTRIGGER (2 PCS); ENG APPR.; MFG APPR.; DWG. NO.; REV; SCALE: 1:4 WEIGHT:; DEC 01/11

MOUNTING TAB (2 PCS)

MATERIAL: C3X6 STEEL CHANNEL

MATERIAL: 5/16 X 2 STEEL BAR

EJECT ROLLER (2 PCS)

MATERIAL: 3/4" CRS ROUND

GUIDE ROD (2 PCS)

MATERIAL: 2" STEEL PIPE (SCH 40)

MATERIAL: 2" CRS ROUND

ROD TOP (2 PCS)

ROD BOTTOM (2 PCS)

UNLESS OTHERWISE SPECIFIED:

OPEN SOURCE RESILIENT LIVING
TITLE:
THE RESILIENT LIVING
CEB PRESS

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

MATERIAL: 1/4" STEEL PLATE

MATERIAL: 3/8" STEEL PLATE

DO NOT SCALE DRAWING
COMMENTS:

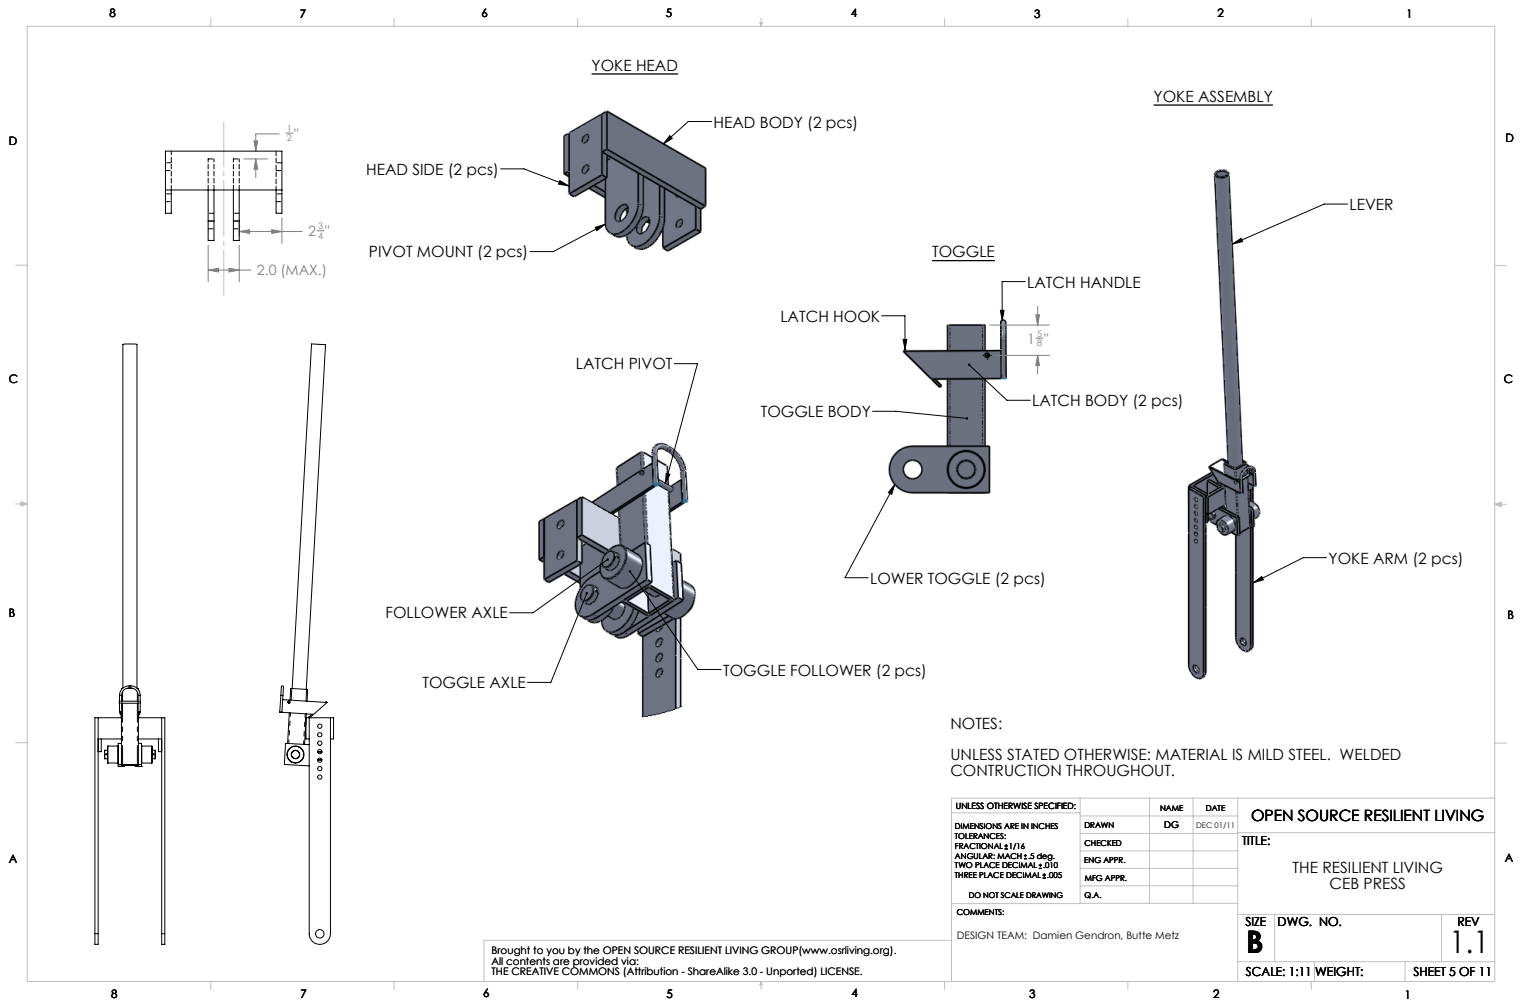
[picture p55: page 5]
FOLLOWER AXLE; TOGGLE AXLE; TOGGLE FOLLOWER (2 pcs); LATCH PIVOT; 2.0 (MAX.); PIVOT MOUNT (2 pcs); TOGGLE BODY; LATCH HOOK; LATCH HANDLE; YOKE ASSEMBLY; YOKE HEAD; ENG APPR.; MFG APPR.; DWG. NO.; REV; SCALE: 1:11 WEIGHT:; DEC 01/11

HEAD BODY (2 pcs)

HEAD SIDE (2 pcs)

LATCH BODY (2 pcs)

YOKE ARM (2 pcs)

LOWER TOGGLE (2 pcs)

NOTES:
UNLESS STATED OTHERWISE: MATERIAL IS MILD STEEL. WELDED
CONTRUCTION THROUGHOUT.

UNLESS OTHERWISE SPECIFIED:

OPEN SOURCE RESILIENT LIVING
TITLE:
THE RESILIENT LIVING
CEB PRESS

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

DO NOT SCALE DRAWING
COMMENTS:

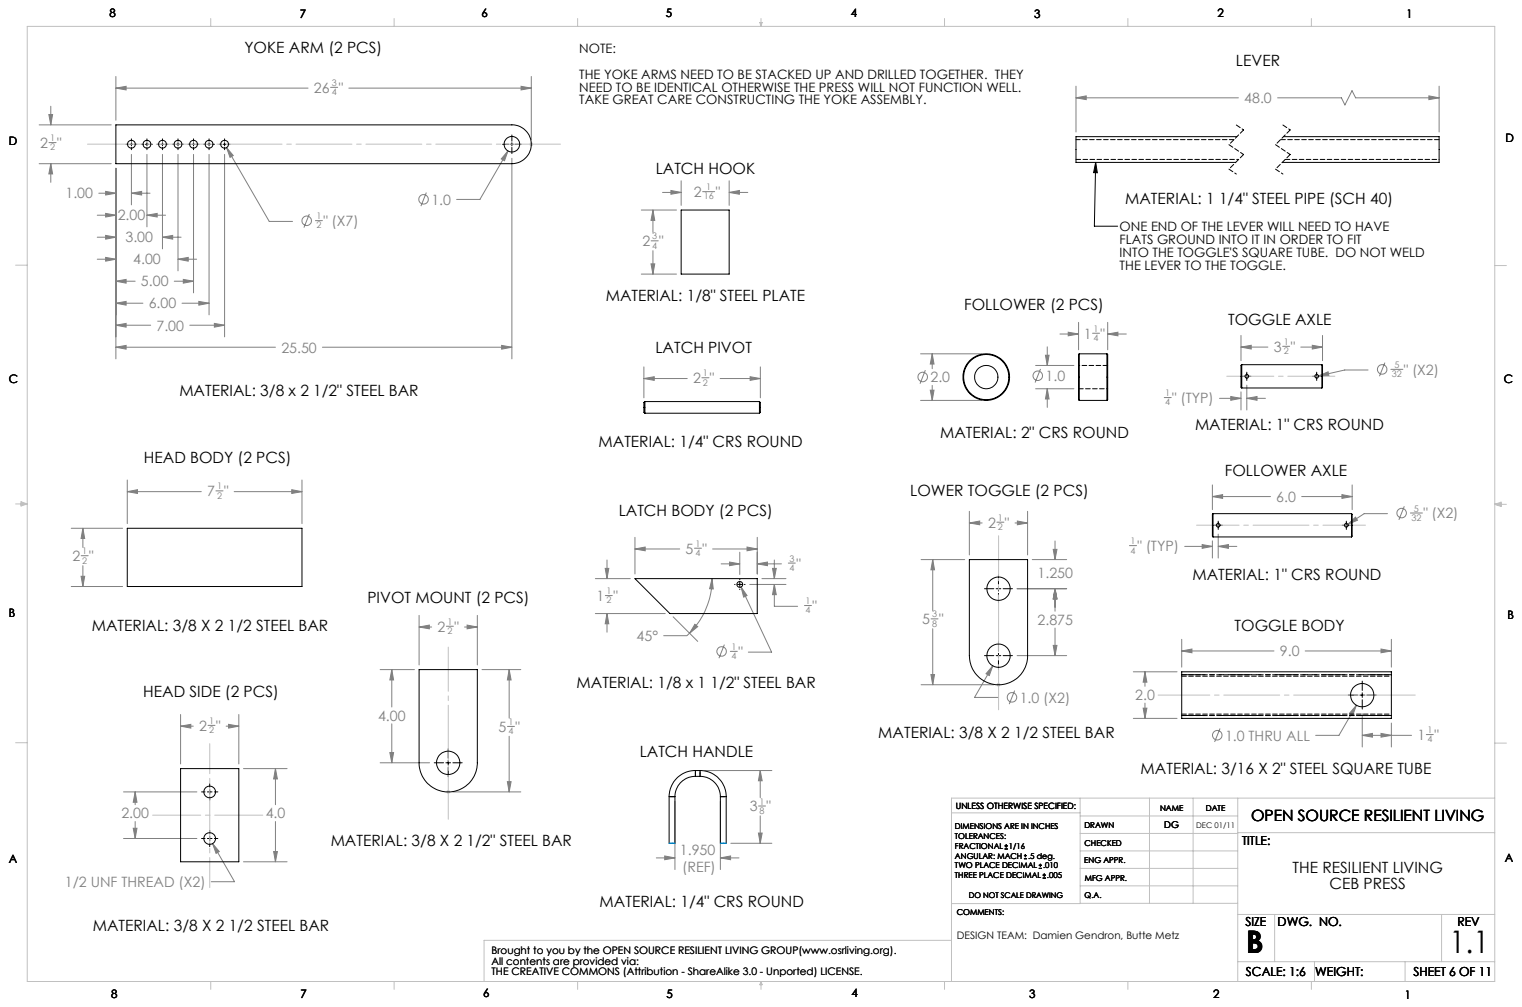
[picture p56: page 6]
LATCH HOOK; 1/2 UNF THREAD (X2); 1 1 1.0 THRU ALL; TOGGLE BODY; 4 " (TYP); FOLLOWER AXLE; MATERIAL: 1" CRS ROUND; FOLLOWER (2 PCS); LATCH PIVOT; YOKE ARM (2 PCS); NOTE:; TOGGLE AXLE; LATCH HANDLE; ENG APPR.; MFG APPR.; DWG. NO.; REV; SCALE: 1:6 WEIGHT:; DEC 01/11

THE YOKE ARMS NEED TO BE STACKED UP AND DRILLED TOGETHER. THEY
NEED TO BE IDENTICAL OTHERWISE THE PRESS WILL NOT FUNCTION WELL.
TAKE GREAT CARE CONSTRUCTING THE YOKE ASSEMBLY.

MATERIAL: 1 1/4" STEEL PIPE (SCH 40)
ONE END OF THE LEVER WILL NEED TO HAVE
FLATS GROUND INTO IT IN ORDER TO FIT
INTO THE TOGGLE'S SQUARE TUBE. DO NOT WELD
THE LEVER TO THE TOGGLE.
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

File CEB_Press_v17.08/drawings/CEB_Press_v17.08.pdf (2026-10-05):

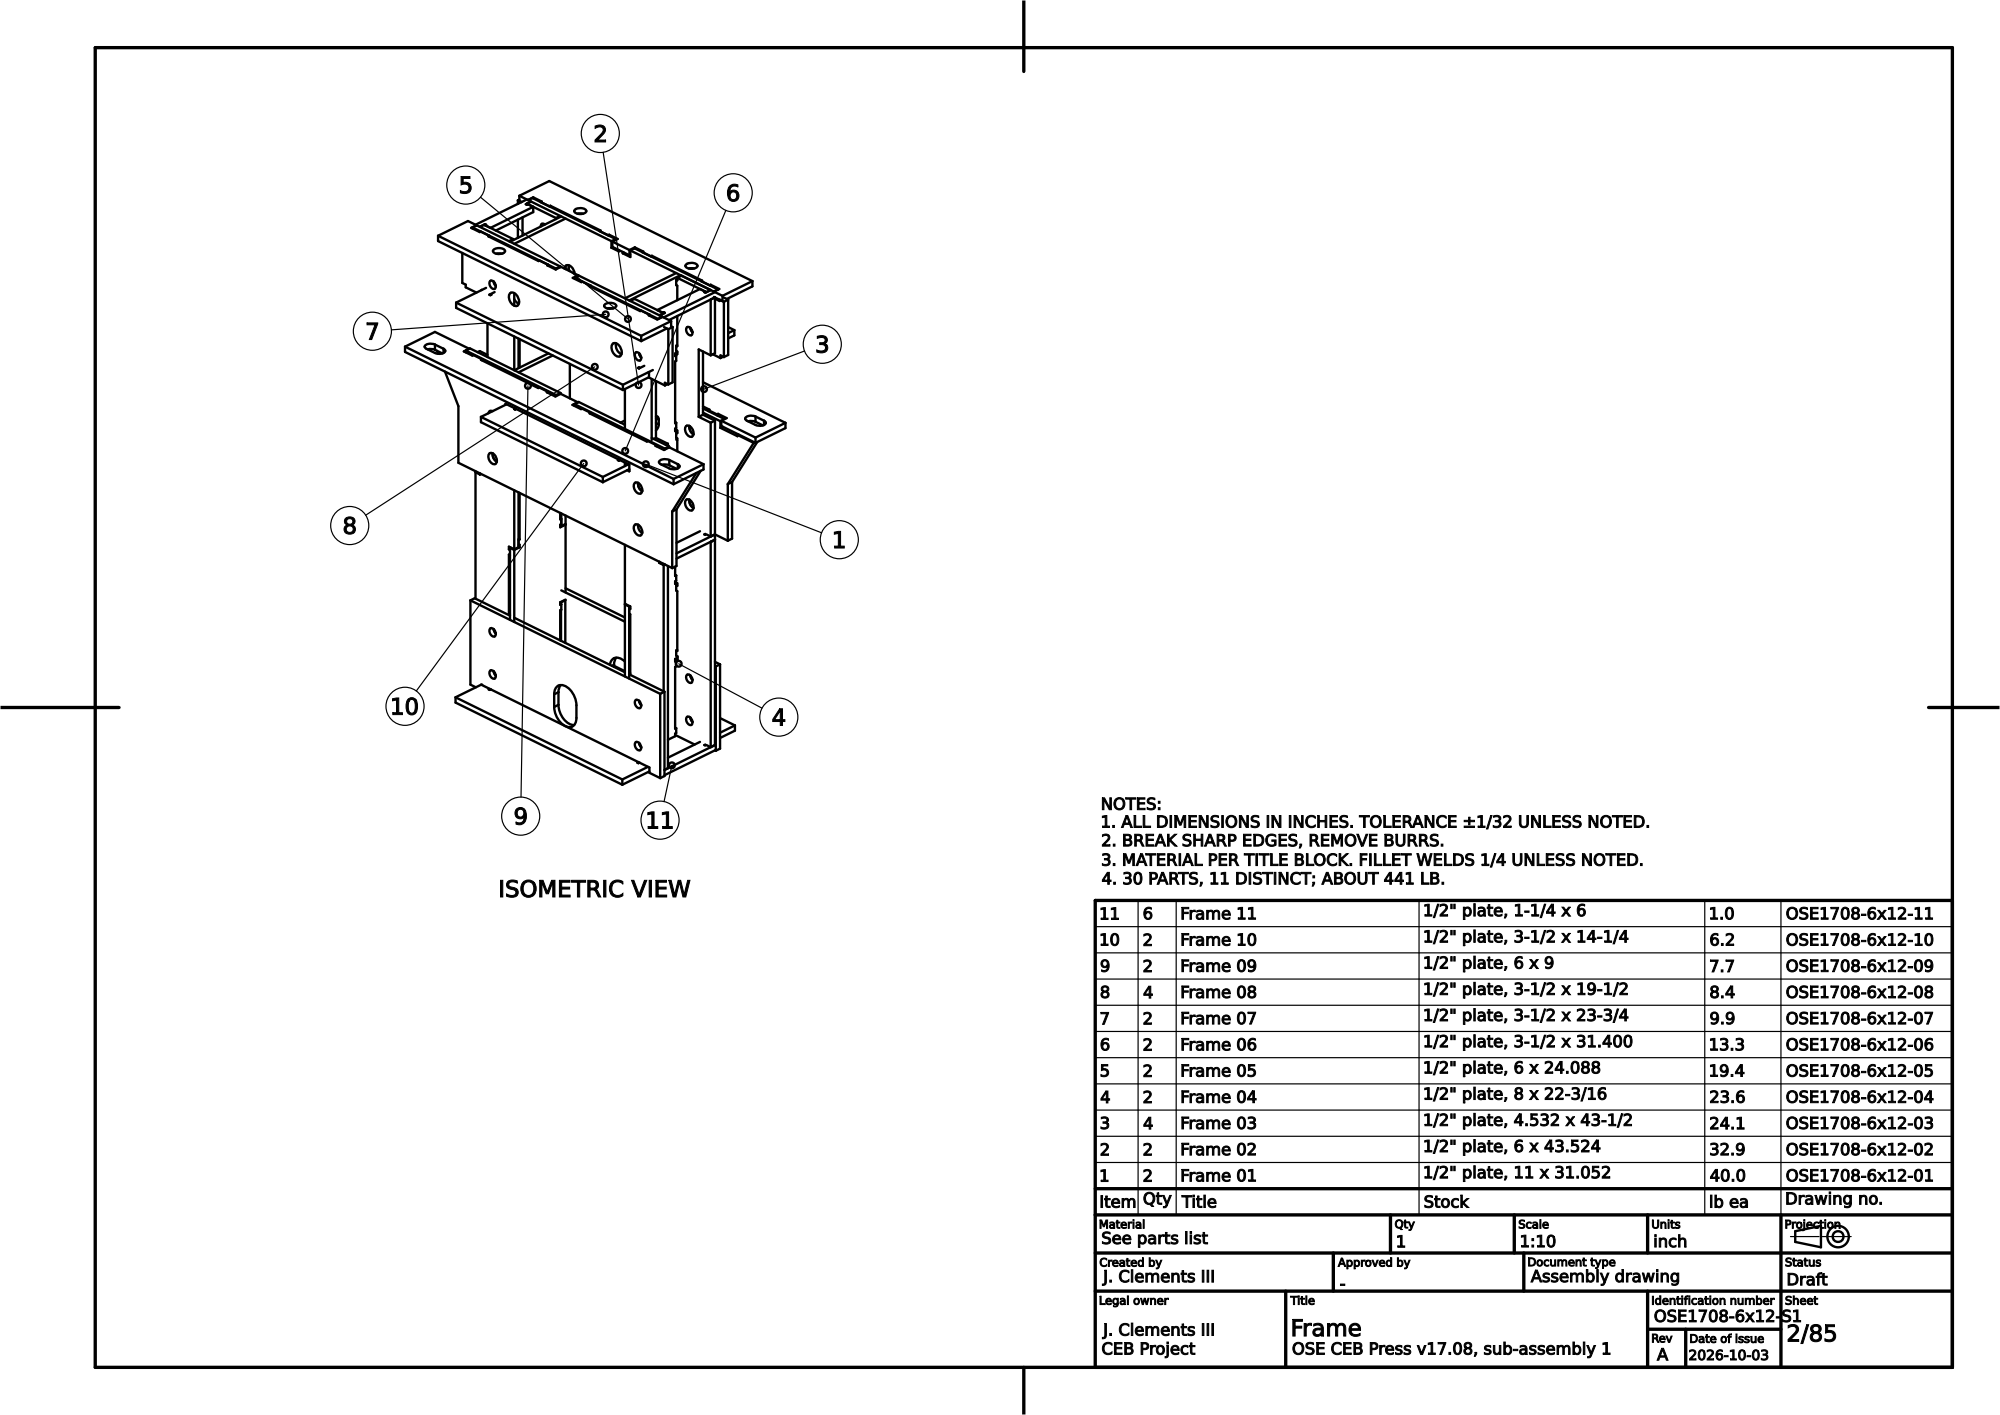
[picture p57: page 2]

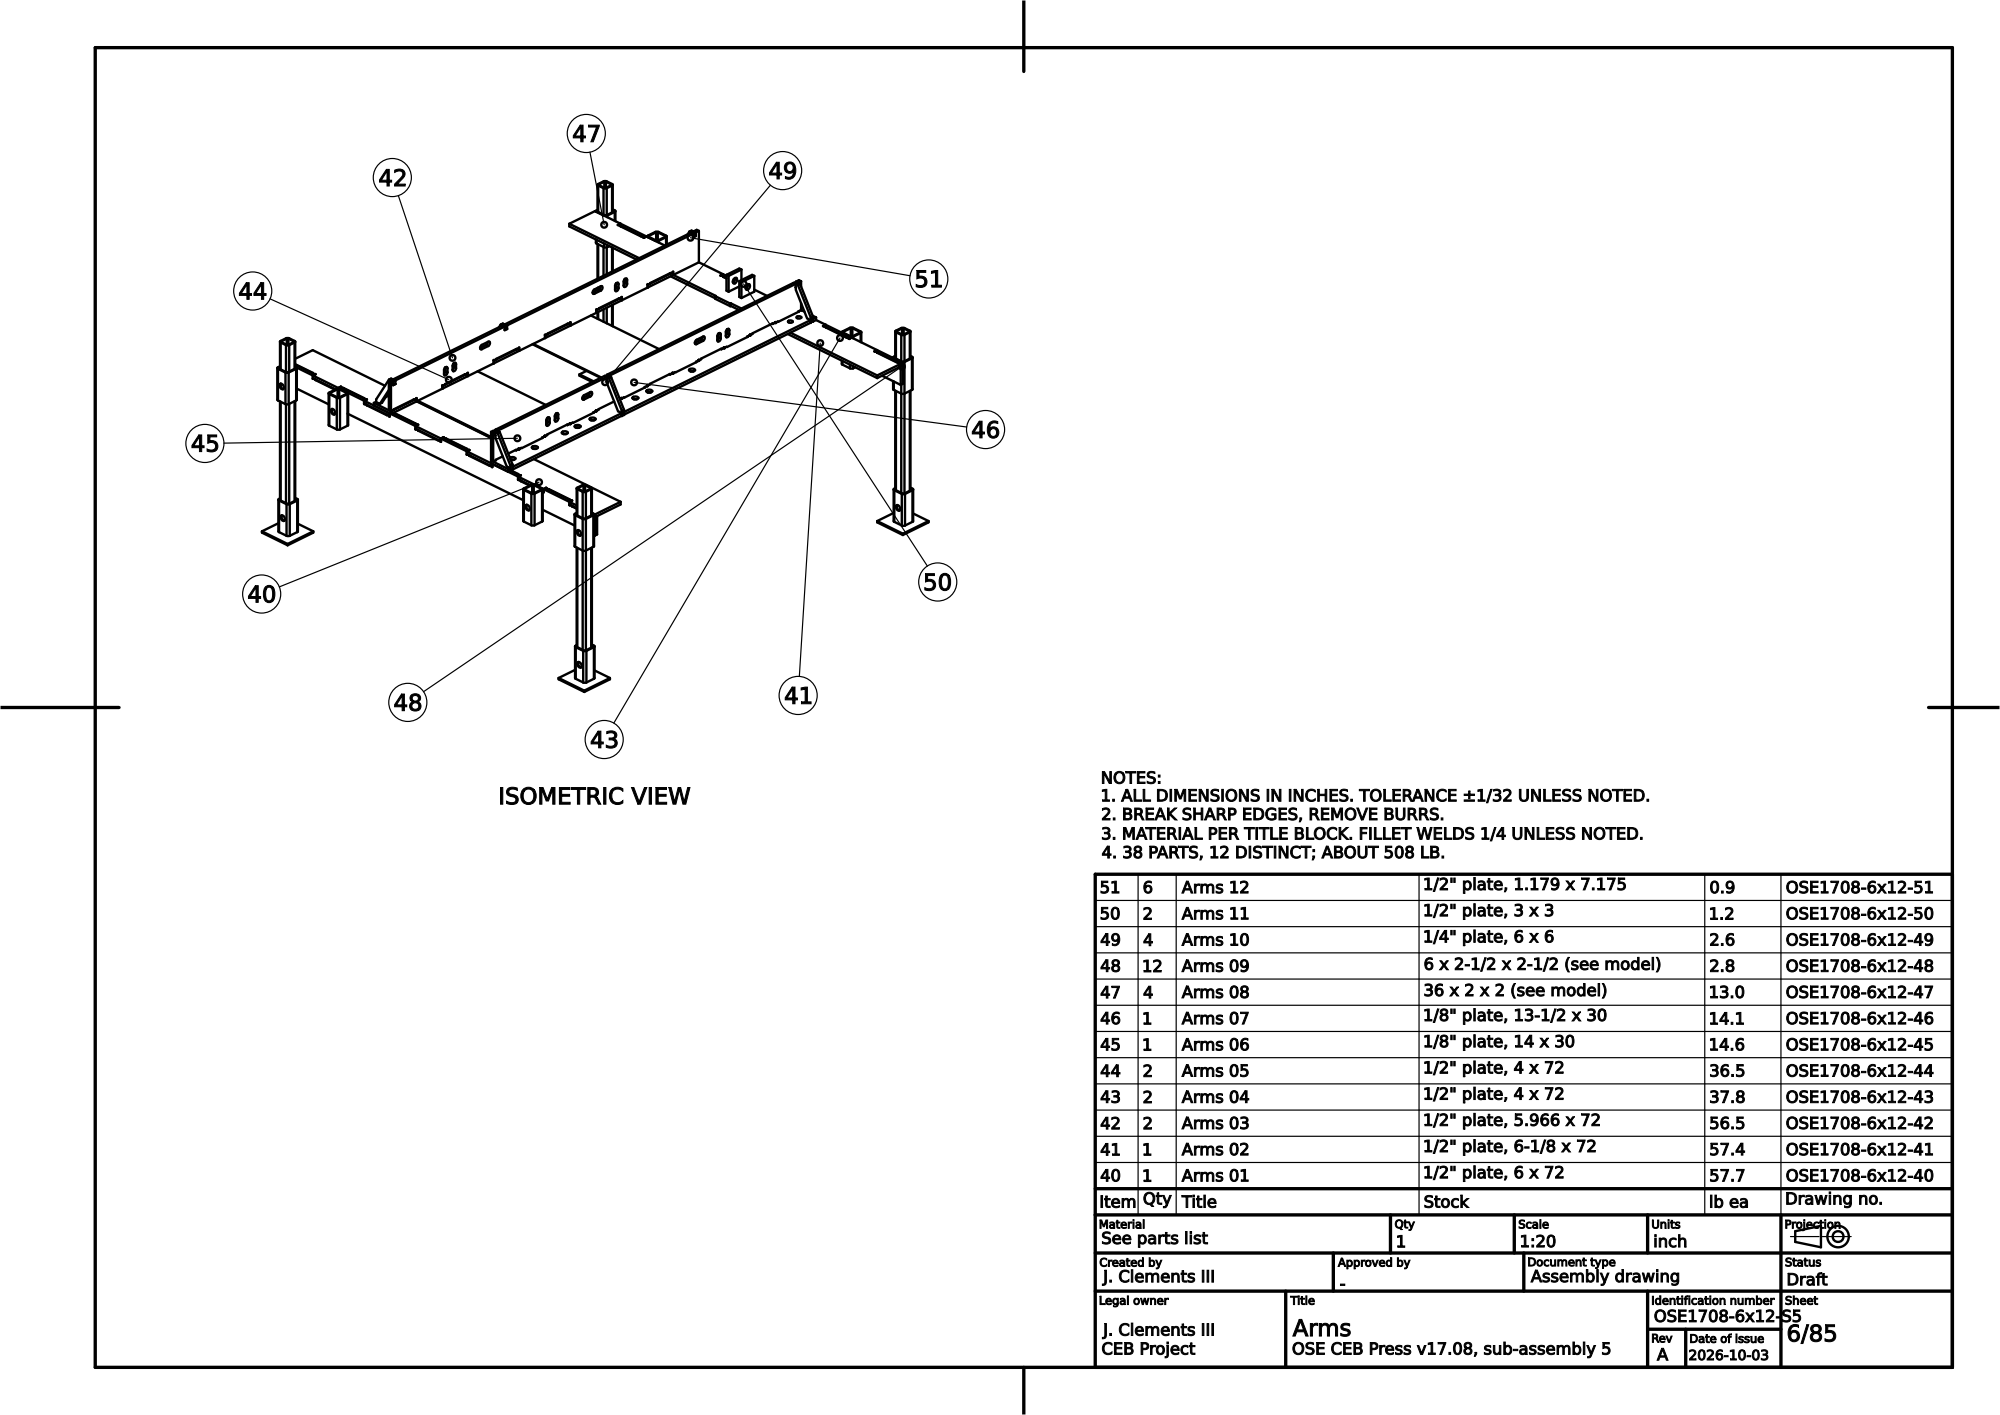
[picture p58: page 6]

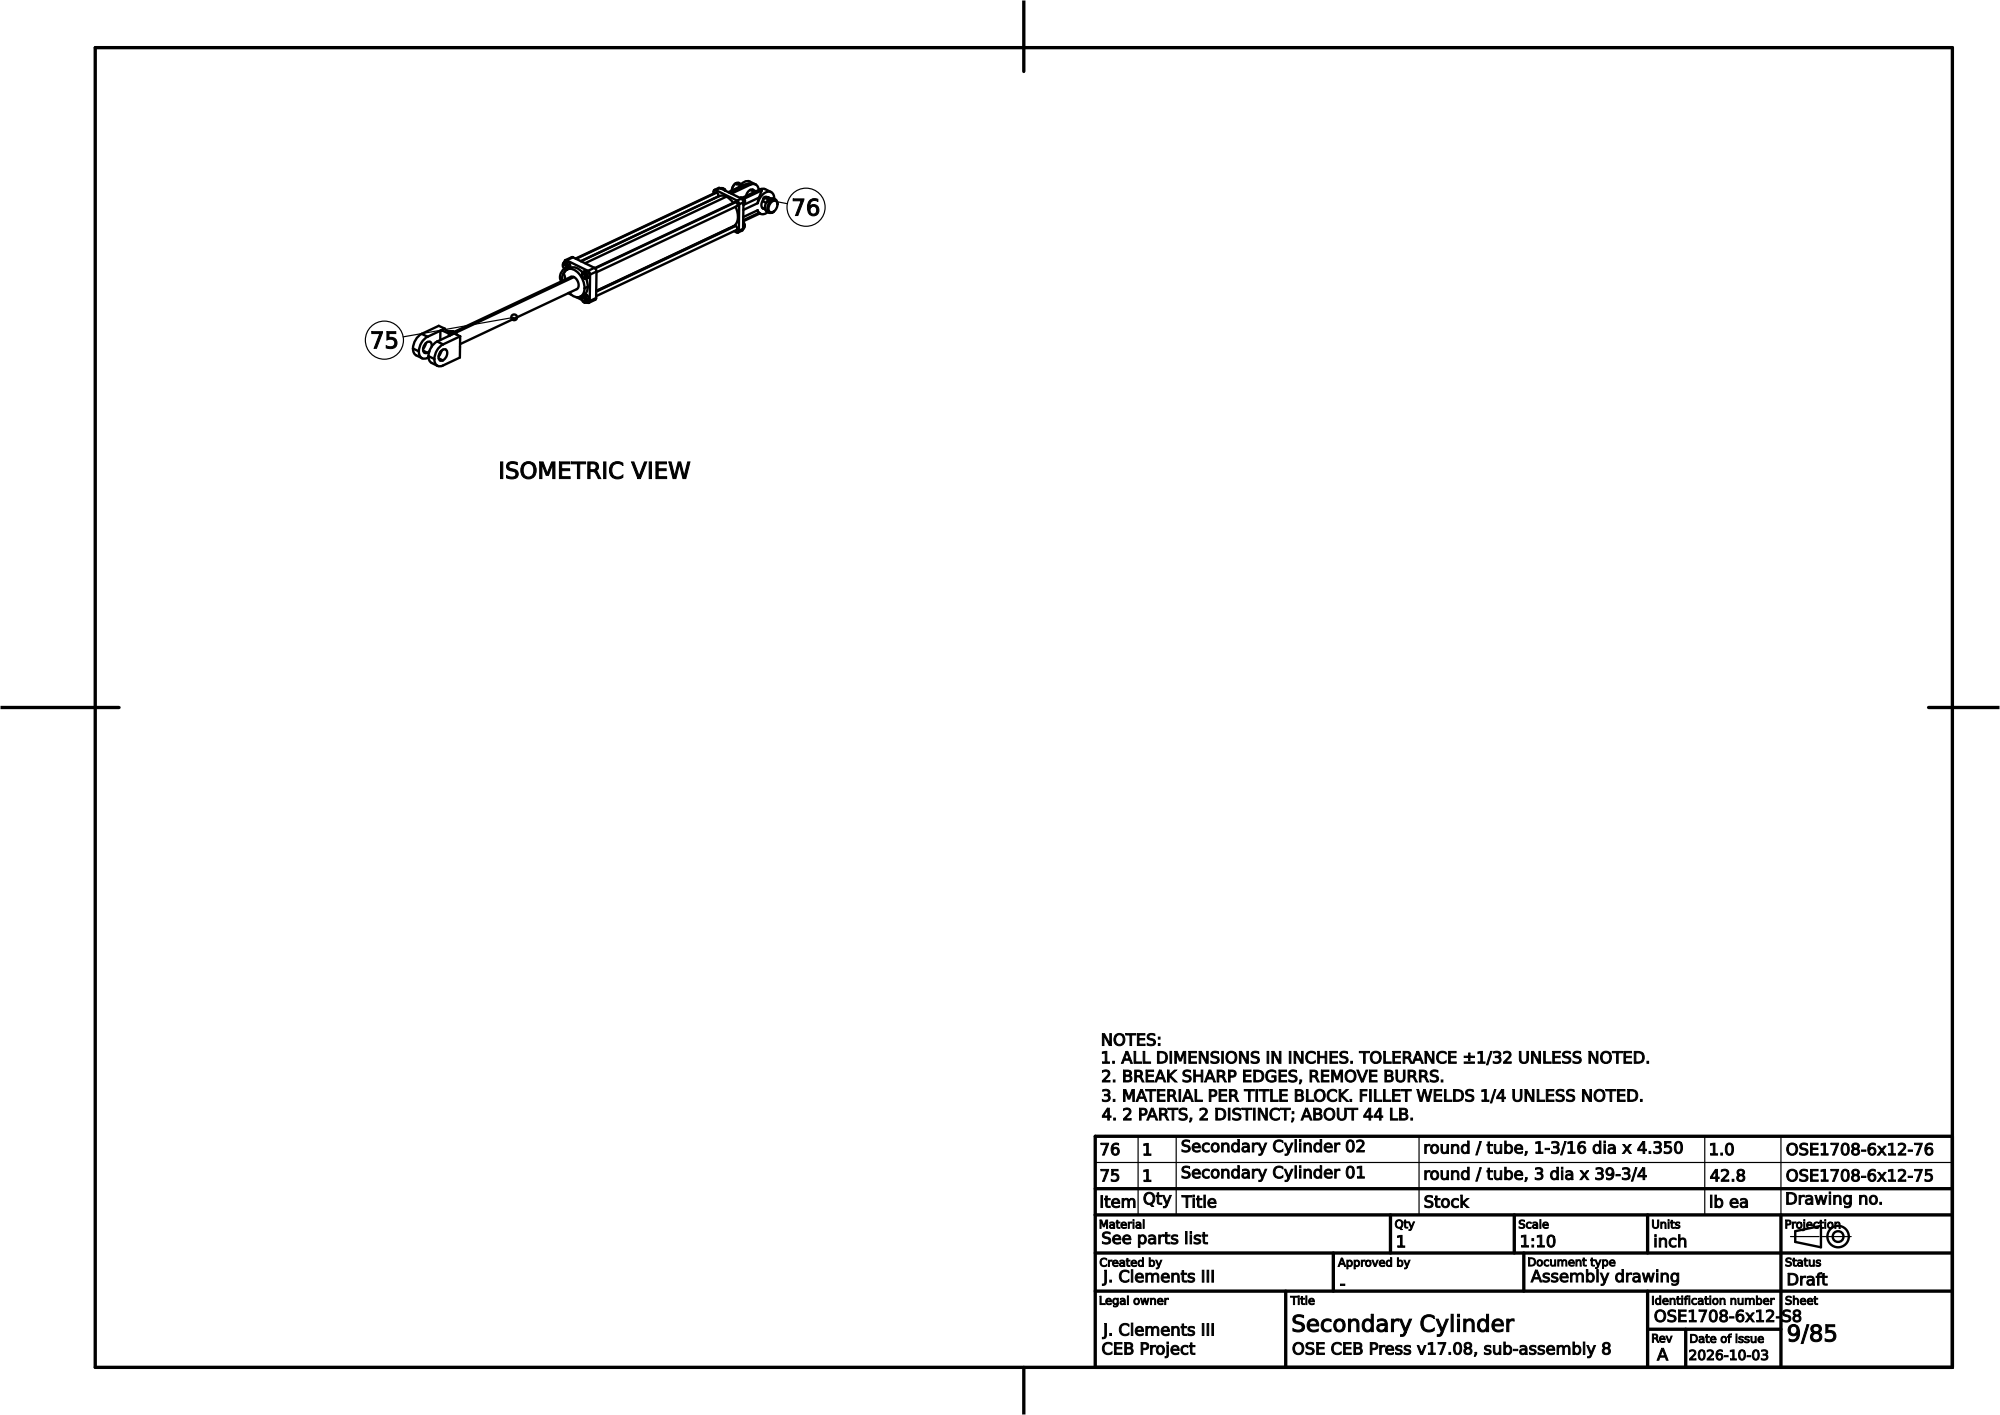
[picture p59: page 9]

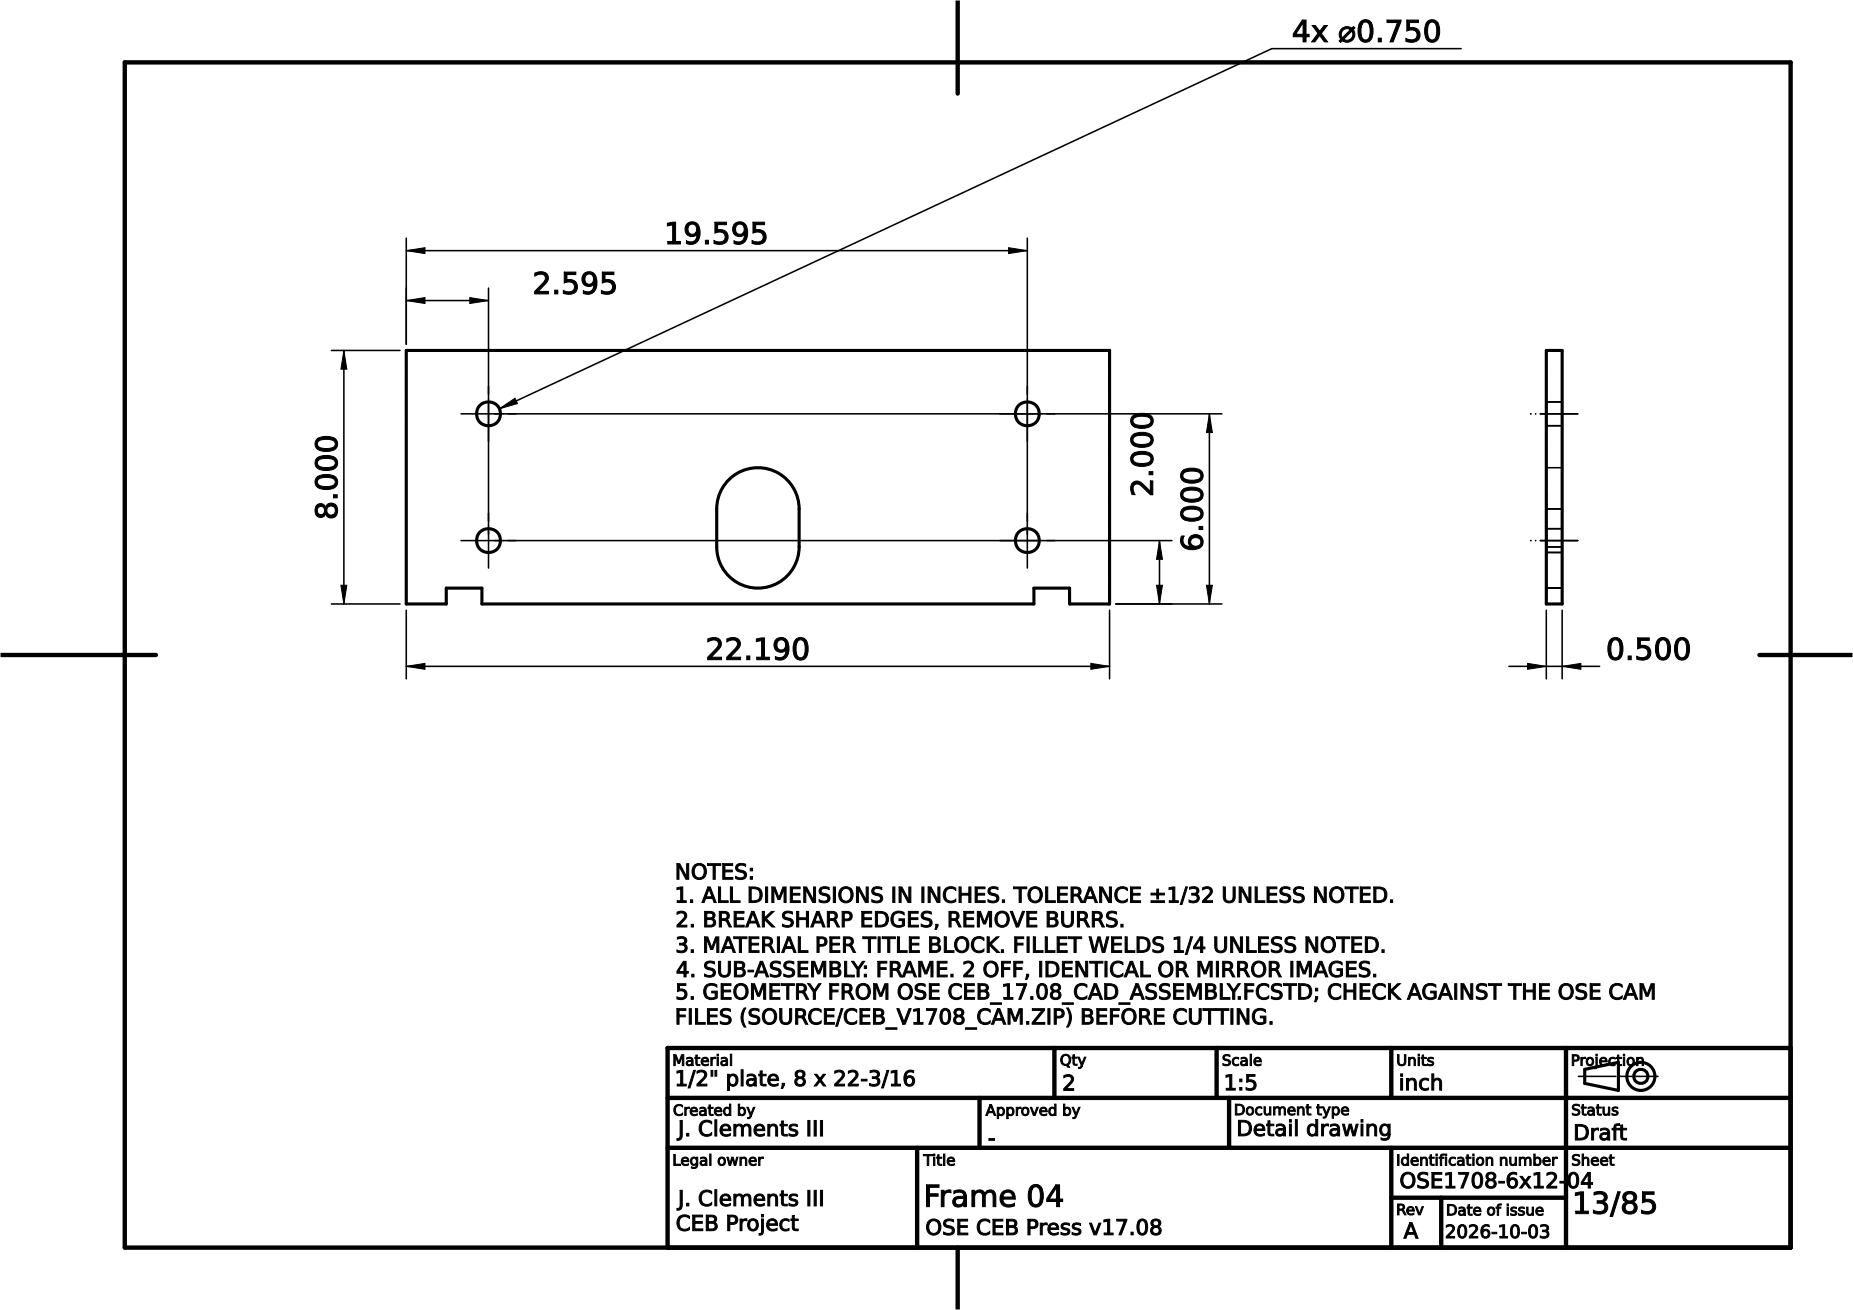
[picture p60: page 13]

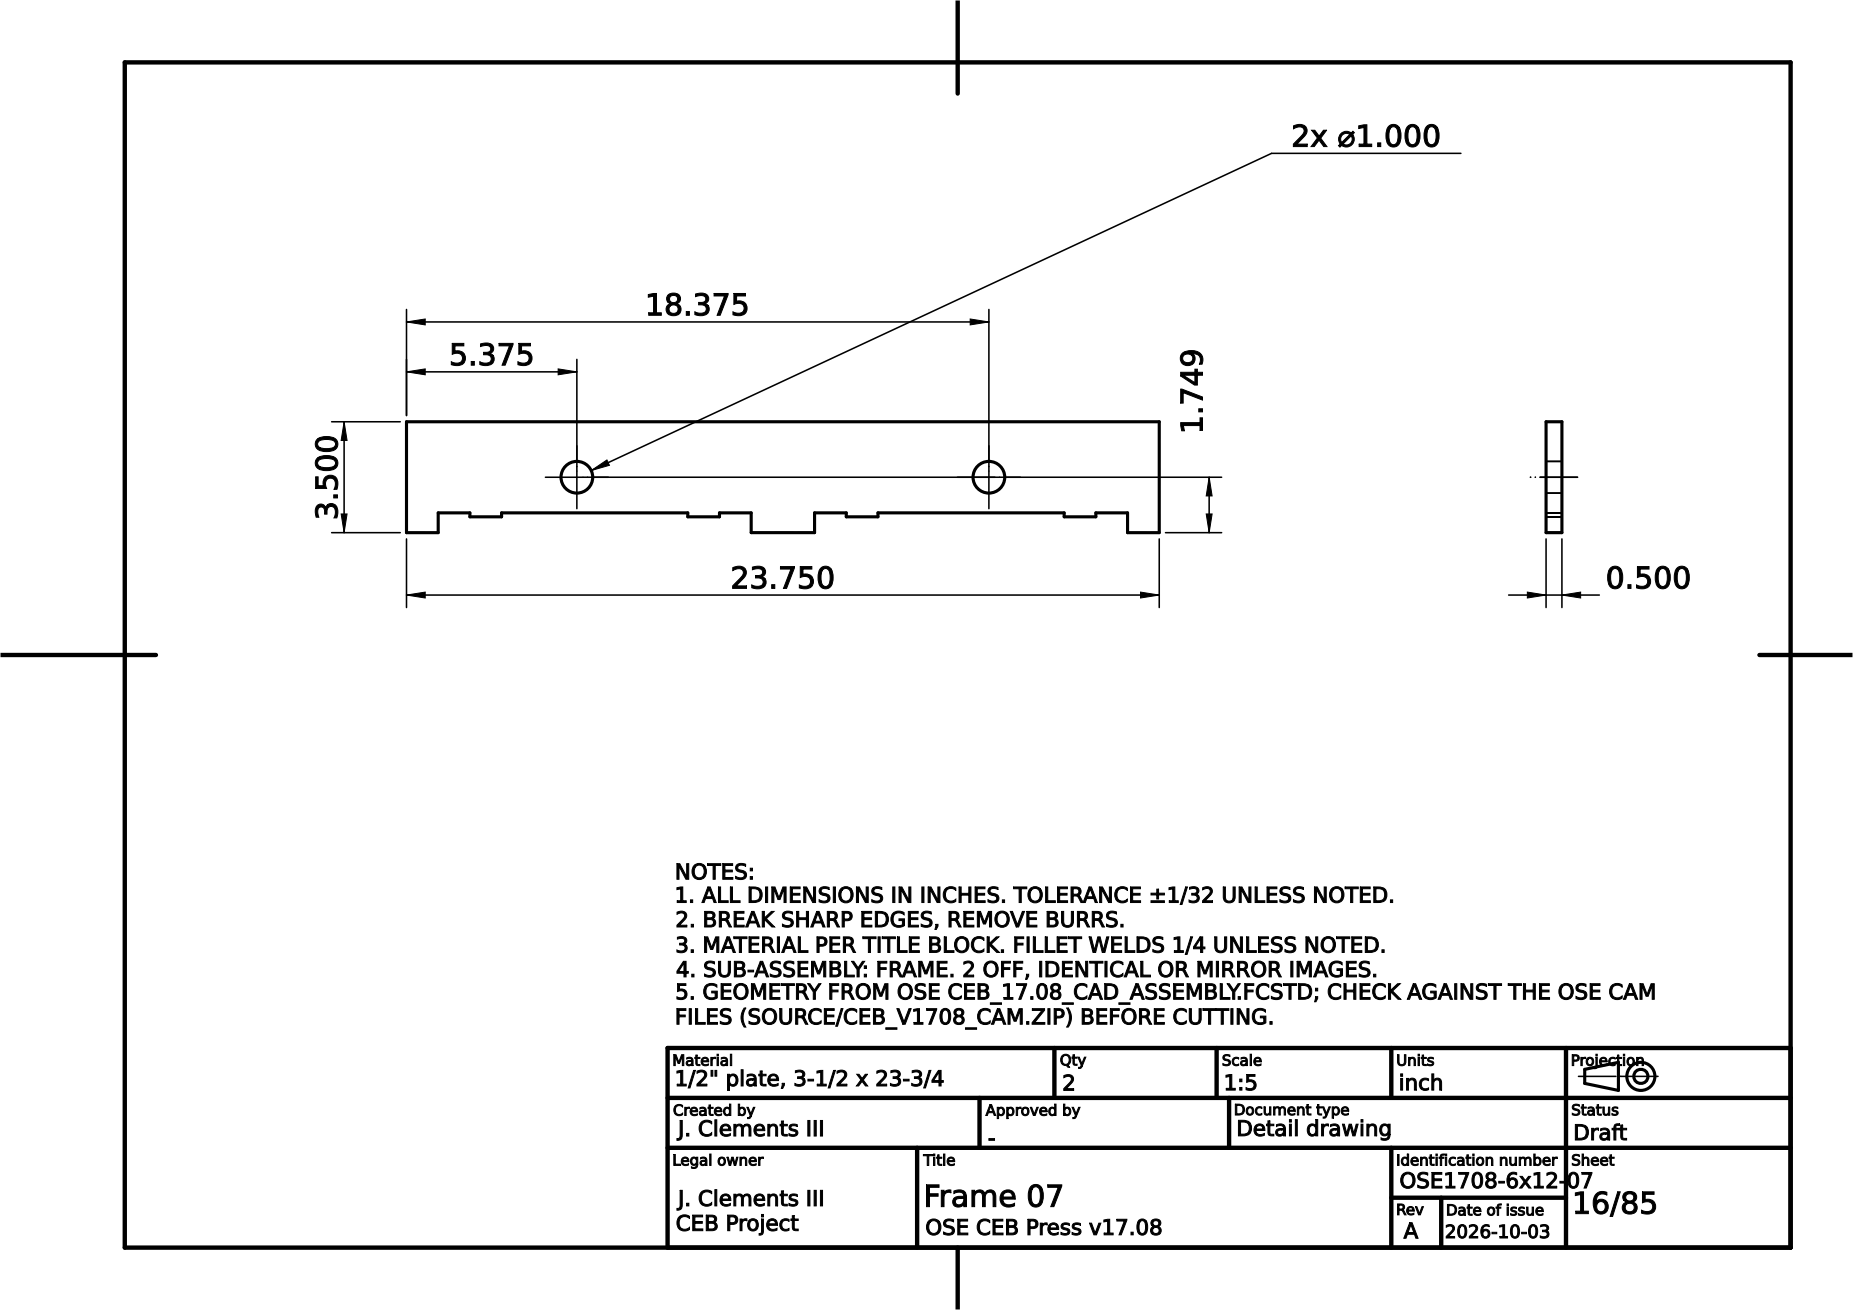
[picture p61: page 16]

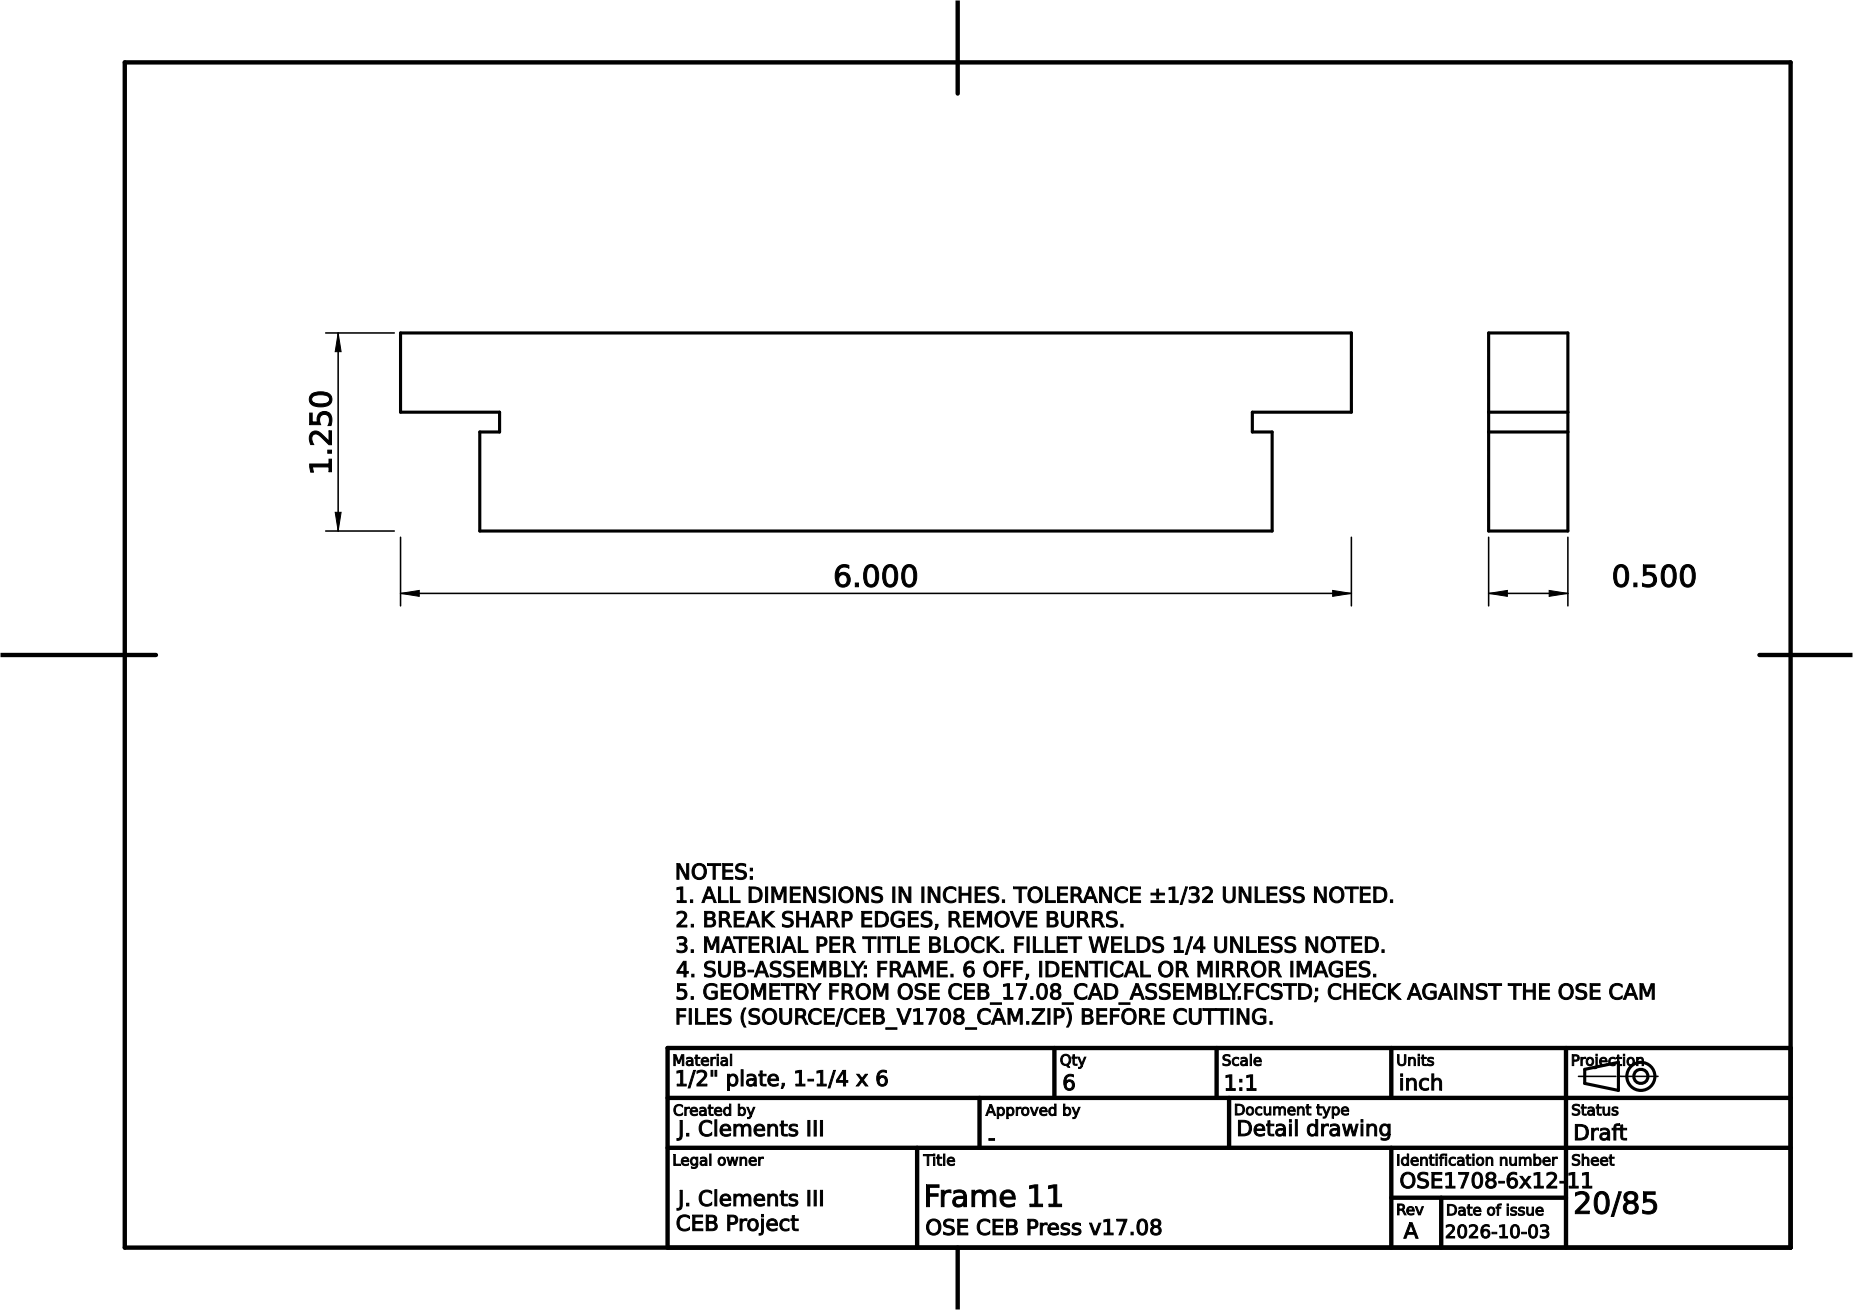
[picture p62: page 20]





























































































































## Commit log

2026-03-10 Initial commit — CINVA-Ram compressed earth block press
    OpenSCAD parametric model with full parts library and assembly.
    Includes FreeCAD macro, engineering drawings, and reference photos.
    [ceb_dome.scad, cinva_assembly.scad, cinva_ram.scad]
2026-03-10 Assembly updates: animation, clamp/pivot geometry, shelf-piston linkage
    - Front block on Pivot: 0.794x2x0.794 → 1x2x1, hole centered vertically
    - Clamp hole repositioned to (0.397, 0.500), R0.25 rounded corners added
    - Lever set to 90°, Spacer block welded between crosses (part of lever)
    - Ramps flipped horizontally, Wings/Tails/Handle recolored to brown
    - Base brackets shifted +4" in X to align with side plates, bolt holes adjusted
    - Piston plates: 7.25x6x0.5 with 1" hole aligned to Load pin
    - Shelf brackets removed (not in drawings)
    - Animation: brown assembly rotates around Spacer pin ($t * 50°)
    - Shelf Z driven by Load pin world Z (piston hole tracks Load pin)
    - Side plates transpare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
    [cinva_ram.scad]
2026-03-10 Fix piston orientation and align teal assembly with load bar
    - Fix syntax error: move lever_bar_profile module out of moving assembly block
    - Move lever variables before press assembly for correct scoping
    - Reorient pistons: vertical plates (6x7.25) rotated 90° with hole near bottom
    - Reduce piston gap by 0.5" (each moved 0.25" inward)
    - Raise shelf (load_pin_z + 6.250) so piston holes align with load bar
    - Raise D_Side slot to barely touch load bar bottom
    - Move fulcrum pin outside moving assembly block
    [cinva_ram.scad]
2026-03-10 Tilt lever to 87° and fix clamp notch alignment on Cross_Front
    - Change lever_angle from 90° to 87° so clamp notch can grab Cross_Front
    - Compute clamp_angle from scoop contact point (segment 2 low end) instead
    of notch opening, so the scoop rests on the cross rather than digging in
    - Remove erroneous -8° fudge factor from clamp angle calculation
    [cinva_ram.scad]
2026-03-12 Rename hinge elements and shape Tab to conform to Receiver
    - Rename hinge parts: Hinge_Pin → Receiver, Hinge_Tab → Tab, pin → Pin
    - Reshape Tab from rectangle to tapered hull: 1" wide at Ramp edge,
    circular end conforming to Receiver OD, with pin hole
    - Update README.md with new hinge part names and descriptions
    [cinva_ram.scad]
2026-03-12 Fix roller/scoop alignment: center scoop at peak, snap roller into scoop
    - Remove 0.125" Y offset from scoop center so it sits at peak surface
    - Add scoop snap logic: roller snaps to scoop center X and bottom Z
    when within scoop zone (internal tangency: R=0.625, r=0.5)
    - Change _t_override default from -1 to 0.5 so default view shows
    roller seated in scoop at ramp peak
    - Update README reference drawing descriptions
    [cinva_ram.scad]
2026-03-12 Swap roller/spacer lengths, make spacer brown, tilt lever to 87°
    - Roller is 6" long (spans between ramps), Spacer is 3" (through Wing/Pivot)
    - Spacer colored brown as part of pivot assembly
    - Lever angle set to 87° so front cross barely touches clamp notch
    [cinva_ram.scad]
2026-03-16 Add CETA-RAM OpenSCAD model with all 6 assemblies
    OpenSCAD parametric model of the CETA-RAM brick making machine based on
    the OHO e.V. engineering drawings (53-page drawing set, CC-BY-SA 4.0).
    Includes all production parts across 6 sub-assemblies: Structure (1.0),
    Top (2.0), Piston (3.0), Support (4.0), Lever (5.0), and Platform (6.0).
    Lever angle is parameterized for animation. All dimensions in mm.
    [ceta_ram.scad]
2026-03-16 Add imperial version of CETA-RAM OpenSCAD model
    Converts all metric steel sizes to standard US imperial equivalents:
    - 13mm plate → 1/2", 10mm → 3/8", 6mm → 1/4"
    - Rods: ∅60→2-3/8", ∅44→1-3/4", ∅32→1-1/4", ∅20→3/4", ∅12→1/2"
    - Tubes: matched OD/ID pairs for pin-in-bushing fits
    - C-channel: 152x52x8 → C6x8.2
    - Bolts: M12/M14 → 1/2"-13
    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
    [ceta_ram_imperial.scad]
2026-03-16 Add FreeCAD parametric model of CETA-RAM with imperial constraints
    FreeCAD Python macro that builds all 6 assemblies (55+ parts) using
    standard US imperial steel sizes. Each part is a named Part::Feature
    with correct dimensions and hole positions. Includes a supplier cut
    list printed on build. Run via Macro → Execute in FreeCAD.
    Key features:
    - All rod/tube OD/ID pairs use matched imperial sizes for proper fits
    - Hole diameters sized for 1/2"-13 bolt clearance
    - Plate thicknesses: 1/2", 3/8", 1/4" standard
    - C6x8.2 channel replaces metric 152x52x8
    - Lever angle parameterized (default 45°)
2026-03-16 Add pre-built FreeCAD file for CETA-RAM imperial model
    Generated from ceta_ram_imperial.py via freecadcmd. Contains all 47
    parts with imperial steel sizes, ready to open in FreeCAD GUI for
    visual inspection and fit verification.
    [CETA_RAM_Imperial.FCStd]
2026-03-16 Add brick comparison and cabin wall assembly notes to README
    CINVA-Ram vs CETA-RAM weight comparison (solid vs cored bricks),
    recommended wall assembly: foam-filled cores + bond beams every 6'.
2026-03-23 Add geodesic dome features: flat base, skylights, doors, and molds
    - Clip base bricks at z=0 for flat ground-level base
    - Rotate icosahedron vertex-up with front pentagon on +X axis
    - Remove pentagons for glass skylights (5 ring + 1 apex smoke hole)
    - Add 3 double doors (52.8"x77.0") at 0°, 144°, -144° under pentagons
    - Door cutouts snap to brick centers for clean half-brick edges
    - Generate ceb_molds.scad with pentagon and hexagon frustum molds
    - Mold shapes use average edge from actual geodesic geometry
    [ceb_dome.scad, ceb_molds.scad]
2026-09-29 Add parametric build123d CINVA-Ram model and ISO 128 drawing set
    Port the CINVA-Ram part library and assembly from cinva_ram.scad to
    build123d with the brick size as a parameter (--brick LxWxH). Mold,
    shelf, top, ramps, end plates, brackets, lever crosses, pin lengths and
    side/base hole positions derive from it; the lever/toggle/clamp
    mechanism stays centred on the mold.
    cinva_drawings.py generates first-angle ISO 128 sheets (line types,
    ISO 7200-style title block, decimal-inch dimensions), a two-sheet
    general assembly with balloons and parts list, DXF flat patterns, a
    multi-page PDF and a coloured STEP assembly. Generated sets for 12x6x4
    and 14x7x4 bricks are in drawings/.
    The port fixes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
    [01_side.dxf, 02_end.dxf, 03_top.dxf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]
2026-09-29 Redesign 14x7x4 press as a working CINVA-Ram mechanism, with checks
    The earlier port kept the SCAD lever geometry, which never moved the
    piston through a compression stroke. Replace it with the real CINVA-Ram
    mechanism: a yoke from the piston pin up to the handle pivot, a saddle
    roller on the handle bearing on AR400 lid ribs, latch pin, and an eject
    roller stand.
    - Roller track is one concave R10 arc: steady piston rise to lock,
    no edges under load; handle locks 3 deg over centre on a stop.
    - Lid hinges at the eject end so pressing loads hold it shut; a tail
    on the hinge lugs stops it open just past vertical.
    - verify() checks brick thickness, rise, lock, lid balance, mold
    cavity and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
    [01_side.dxf, 02_end.dxf, 03_top.dxf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]
2026-09-30 Add central claw latch, assembly guide and 3D animation
    - Central CINVA-style latch: one gravity claw (two plates + thumb bar)
    pivots on a tie between horns on the yoke bars and hooks a catch bar
    between the handle cheeks. The claw arm lies along the catch bar's
    path so latch loads cannot pry it open; a counterweight tail keeps it
    shut at every tilt, and it flips open onto a stop rod for pressing.
    The tie and stop rod make the yoke one rigid frame.
    - Handle bridges moved out of the claw's swing; lid rib gets a knee and
    lower eject end, lid hinge lugs trimmed, for catch-bar clearance.
    - verify() adds claw checks; strength table adds latch parts at a
    2,000 lbf ejection load. 188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
    [01_side.dxf, 02_end.dxf, 08_wlug.dxf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]
2026-10-01 Add simple 14x7x4 press: faithful scale-up of the permies CINVA-Ram replica
    cinva_simple.py scales every part on cinva1-7.jpg from his 11.5x6x3-5/8
    brick to 14x7x4. It uses his knee mechanism: the cam pin seats in the V-ramp
    scoop, his hook latch holds the head, and the eject levers over the fixed
    pins.
    It fixes his 2" side slot, keeps the slot top below the soil, sets the
    fixed-pin height for the eject stroke, and uses heavier stock where 200 psi
    on a 14x7 brick needs it. A horseshoe lid handle is added.
    The full check passes: kinematics, strength and the collision sweep.
    Drawings (27 sheets, PDF, STEP, DXF) are in drawings/simple-14x7x4.
    cinva_drawings.py and cinva_animation.py gain --m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
    [01_side.dxf, 02_end.dxf, 06_lid.dxf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]
2026-10-03 drawings: per-sheet revision and issue date from model hooks (REVISIONS, CURRENT_REV, SHEET_REV); manifest records rev; note 3 'Material per title block' (was A36 / 1018 on 4140 and AR400 parts)
2026-10-03 ECP rev B: cam pin 1-3/8, side plates 5/8
    Trade study (sysml_trade.py): min stress margin +6.0% -> +14.7% (now piston cap),
    steel 230.5 -> 248.1 lb. Handle pull 163.5 lbf, kinematics unchanged (cam arm 2.1322,
    poses identical). Geometry changed on 11 parts: side, fpin, gpin, lid, ramp, xbar,
    ppin, cheek, campin, bridge, lpin.
    - cinva_simple.py: Params; REVISIONS / CURRENT_REV = B
    - CinvaRam.sysml: sysml_sync --update; SteelBudget placeholder 240 -> 250 lb
    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
    [01_side.dxf, 02_end.dxf, 06_lid.dxf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]
2026-10-03 ci: pin build123d 0.11.1 (cinva_drawings uses Vertex.to_tuple, removed in 0.12)
2026-10-03 drawings: parts list row height fits the sheet; steel weight split press / attachments (ATTACHMENT_GROUPS hook)
2026-10-03 Feeder rev C: funnel on a sliding feed box with a knife-gate floor (items 24-38)
    Parks on the +Y side (everything moving above the mold stays within |y| 5.31;
    lid swings over +X, yoke leans over -X) and slides across the mold at fill only.
    Knife gate seals the box over the y 4.125-5.875 strip that the arms, Q stubs and
    lid straps sweep, and shears the charge off at the mold top when pushed shut.
    Pin end: 3/4 lip + 45 deg chute under the head cheek tips. Funnel flares 30 deg
    toward the operator. Rail bracket / stop post on the side plates at x 9.25-11.25.
    - capacity 1,499 cu in = 2.27 loose charges; about 53 lb steel
    - slide and gate travel clear at fill, min running clearance 0.357 (need 0.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
    [01_side.dxf, 02_end.dxf, 06_lid.dxf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]
2026-10-03 Requirements: replace placeholder limits with sourced ones
    HandleForceLimit 165 -> 120 lbf: CCOHS Table 2 'pull down, above head height'
    (540 N, from Kodak Ergonomic Design for People at Work). The peak pull comes 71%
    through the head rotation with the grip ~67 in up, not at the end of the stroke.
    FAILS at 200 psi (163.5 lbf): one operator needs <= 147 psi, or two operators,
    or a 98 in handle.
    SteelBudget (250 lb, no basis) -> PartHandlingLimit: heaviest single part <=
    51 lb, NIOSH RNLE load constant (23 kg). Passes: side plate 40.7 lb. Total
    steel reported, not capped.
    ASSEMBLY.md Step 8: corrected where the peak force occurs; added the limit.
2026-10-03 drawings: design-sheet chart emphasizes the working pressure (was hard-coded 200 psi), legend marks it
2026-10-03 Rev D: working pressure 200 -> 150 psi, handle 72 -> 74 in
    Peak pull 119.3 lbf, under the CCOHS 120 lbf limit for pulling down above head
    height (HandleForceLimit now passes; sync exit 0). Margin is 0.7 lbf.
    Handle pipe 64 -> 66 in. Eject force 112 -> 109 lbf. Strength checks unchanged
    (306 psi design load).
    Rev D on the 5 sheets whose content changed (general assembly, assembly views,
    operating positions, design data, handle); the rest stay rev C.
    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
    [Simple-CINVA-Ram_14x7x4.step]
2026-10-03 Rev E: handle 74 -> 90 in, 1-1/2 -> 2 sch 80; bridges moved; handle bending check
    Handle 90 in puts the peak grip at about 76 in for a 6'1" operator: peak pull
    98 lbf at 150 psi, 190 at 290 psi (CINVA level). Eject 112 -> 92 lbf.
    New check: handle bending at the bridge. The moment at the head is force x
    length, the same for any handle length; 1-1/2 sch 80 was at 39 ksi against
    23.1 allowable at the 306 psi design load (yields near 290 psi). 2 sch 80:
    21.5 ksi. This was missing from every earlier revision.
    Bridges 2.0 -> 3.375 wide for the bigger bore, moved from 8.0/9.75 to
    9.25/11.5 from Q (the open latch bar hit the inner one); cheek handle leg
    10.5 -> 12. Full sweep clear, lock unchange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
    [15_cheek.dxf, 18_bridge.dxf, Simple-CINVA-Ram_14x7x4.step]
2026-10-03 tooling: title-block date fits its cell; animation feed/gate columns and feeder/gate groups; trade limit read from the model; sync reports mass per attachment group
2026-10-03 Rev F: stand detailed; side-plate sheet fixes; feeder animated and modeled
    Stand (items 39-42, 56 lb): 3x2 rect tube rails carry the side plates and
    foot clips (clip bolt holes), 2x2 cross tubes at the fixed-pin end, under the
    lid end of the mold and under the open lid's touchdown (x ~23.8), corner legs
    and foot plates. Full sweep clear; the yoke arms pass 0.16 above the top at
    eject (ASSEMBLY.md Step 10: nothing proud of the top). Replaces the placeholder
    block in the animation.
    Side plate sheet: feeder hole dimensions added (missing since rev C); lid pivot
    and slot leaders re-routed clear of geometry and each other.
    Animation: fill step now pushes the box over, opens and shuts the gate,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
    [01_side.dxf, 02_end.dxf, 06_lid.dxf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]
2026-10-03 Rev G: handle 2 sch 80 -> 2 sch 160
    Bending at the bridge 21.5 -> 16.0 ksi at the 306 psi design load (margin +7% ->
    +44%). Handle 33.8 -> 50.3 lb: now the heaviest part, 0.7 lb under the 51 lb
    NIOSH single-part limit; about 25 lbf at the grip to lift it back past upright.
    Same OD, so bridges, cheeks and clearances unchanged.
    Rev G on the 4 sheets whose content changed.
    [Simple-CINVA-Ram_14x7x4.step]
2026-10-04 Animation: default view from the front side like the makers' photos
    The viewer takes view_target and views from the press metadata; the simple
    press opens with its long side facing the camera, a little above, the
    handle rising on the left.
2026-10-04 OSE CEB Press v17.08: ISO 128 drawing set from OSE's FreeCAD model, plus the a-z soil shaker
    - CEB_Press_v17.08/v1708_drawings.py: general assembly, 8 sub-assembly sheets, 76 part sheets
    (246 pieces), DXF, PDF, STEP from CEB_17.08_CAD_Assembly.fcstd
    - CEB_Press_v17.08/shaker/shaker.py: soil shaker from the CEB a-z Build 1.0 manual and OSE
    weldments 001-0042..0048, 0077 (9 parts, 10 sheets)
    - OSE source files (wiki downloads, sub-assembly FCStd files)
    - cinva_drawings.cylinders(): skip cylinder faces without a radius (scaled imported BREPs)
    [#midplatetop.dxf, 01_frame_01.dxf, 02_frame_02.dxf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]
2026-10-05 Drawing library: OSRL press, OSE Press 6 (a-z), v17.08 animation with shaker, multi-machine web page
    - osrl/: OSRL Resilient Living CEB press rev 1.1 as build123d (model, functional/strength/clearance
    checks, 46-sheet ISO 128 set, animation, README with design findings)
    - press6/: OSE CEB Press 6 from full_assembly.stp named via the a-z cut list, drawing index and DXF
    labels (94 sheets, DXF cross-check, README with gaps vs the a-z manual)
    - animation/ + v1708_animation.py: v17.08 press cycle with the soil shaker
    - index.html + site/: drawing library for v17.08, Press 6, OSRL and the shaker (thumbnails, parts
    table, sheet viewer with deep links)
    - source PDFs and CEB Press.ods (a-z cut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
    [01_01_014_00_0_lf1.dxf, 01_frame_01.dxf, 02_01_034_00_0_lf12.dxf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]
2026-10-05 Stop tracking generated STEP exports; Press 6 script fetches OSE sources when OSE/ is absent
    - .gitignore: drawings/**/*.step and CEB_Press_v17.08/*/drawings/*.step (rebuilt by the drawing scripts)
    - press6_drawings.py: ensure_sources() downloads OSE's 01-001-00-6.stp, 2D drawing zip and CNC DXF
    libraries from the OSE wiki into press6/source/ose/ (gitignored) if OSE/ is not there; drawing index
    and DXF extractor now kept in press6/
    [CEB_Shaker.step, CINVA-Ram_14x7x4.step, OSRL-CEB-Press_12x6x4.step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]
